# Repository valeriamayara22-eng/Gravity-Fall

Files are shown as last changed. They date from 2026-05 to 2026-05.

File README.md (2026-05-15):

# Gravity Fall: Gravitational Energy Storage System

**An open-source mechanical battery that converts gravitational potential energy into usable electricity.**






---

## Overview

Gravity Fall is a gravitational energy storage system designed and built by high school students in Mexico City. It demonstrates that gravitational potential energy can be reliably converted into usable electrical power — no solar panels, no wind turbines, no lithium batteries required.

The system works like a **mechanical battery**: a 15.65 kg mass is lifted to a height of 1.80 m. As it descends through a chain-driven transmission system, it spins a hub motor that generates electricity. A magnetic braking system controls the descent speed, while an MPPT charge controller regulates the output for stable energy storage.

**Key results:**
- Peak electrical output: **13W** at 1.02 N·m torque
- System efficiency: **58%** (gravitational PE → electrical energy)
- Angular velocity stabilization at **15.65 kg**, confirming successful magnetic brake control
- Stable descent time of **9.5 seconds** per cycle, validated by MPPT algorithm

> **⚠️ Important note:** This is a proof-of-concept prototype for energy storage research, not a practical energy generation device. Each 9.5-second descent cycle produces approximately 123.5 J of usable electrical energy. To fully charge an iPhone 16 (12.54 Wh battery), the mass would need to be lifted and released **394 times**. The value of this project lies in validating the physics, the control system, and the efficiency of gravitational-to-electrical conversion at small scale — not in replacing existing charging methods. The engineering challenge ahead is scaling: heavier masses, taller structures, and automated return systems could make this approach practical for real-world energy storage.

---

## The Problem

Over 770 million people worldwide lack access to reliable electricity. Existing renewable solutions (solar, wind) depend on weather conditions and often require expensive lithium-ion batteries for storage — batteries that degrade over time, require rare minerals to produce, and generate toxic waste.

Gravity Fall proposes an alternative: **store energy as height**. Unlike chemical batteries, a mass doesn't degrade. It can be lifted and dropped thousands of times with zero loss of storage capacity. The system requires no fuel, no rare materials, and no grid connection.

---

## System Architecture

```
┌─────────────┐
│  Mass (15.65 kg)  │
│  Height: 1.80 m   │
│  Ug = mgh         │
└───────┬─────┘
        │ Descent (gravity)
        ▼
┌─────────────┐
│  Chain Drive      │
│  Ratio: 1:9       │
│  Chains  │
└───────┬─────┘
        │ Mechanical torque
        ▼
┌─────────────┐
│  Hub Motor        │
│  Multi-pole       │
│  Magnetic brake   │
└───────┬─────┘
        │ AC output
        ▼
┌─────────────┐
│  MPPT Controller  │
│  Charge regulation│
└───────┬─────┘
        │ Regulated DC
        ▼
┌─────────────┐
│  LiFePO4 Battery  │
│  12V storage      │
└───────┬─────┘
        │ DC-DC conversion
        ▼
┌─────────────┐
│  USB-C Output     │
│  5V / Device      │
│  charging         │
└─────────────┘
```

---

## Prototype

| | |
|:---:|:---:|
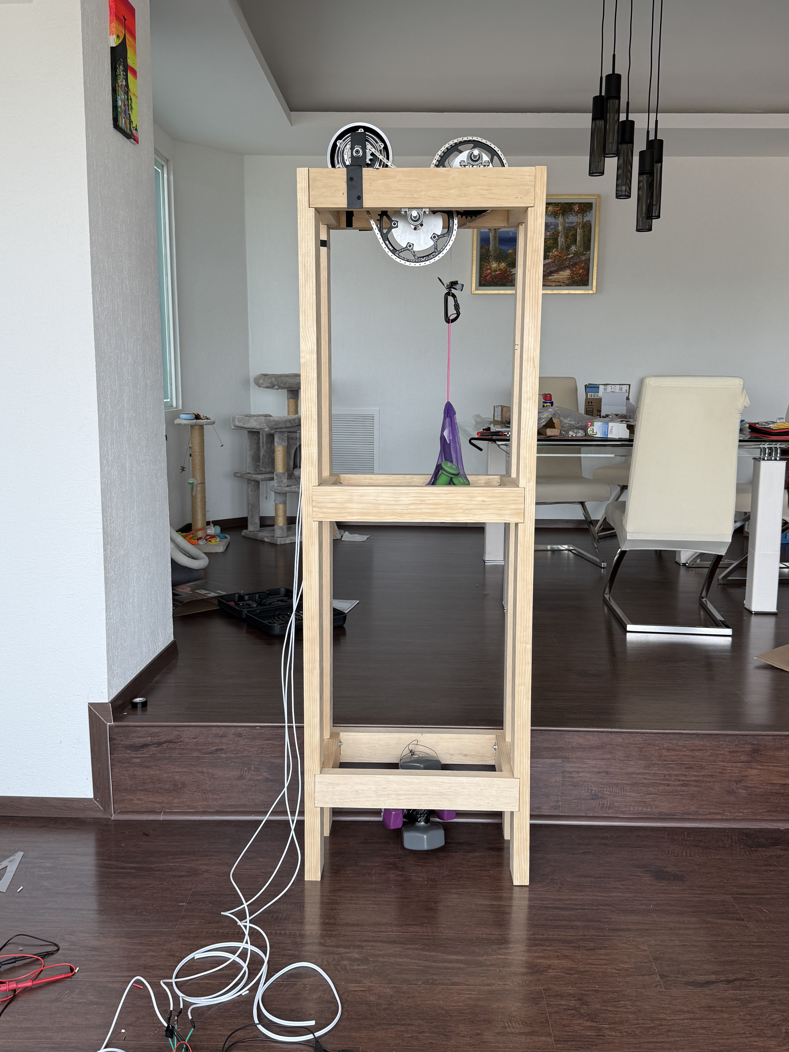
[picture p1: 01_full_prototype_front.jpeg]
Full prototype
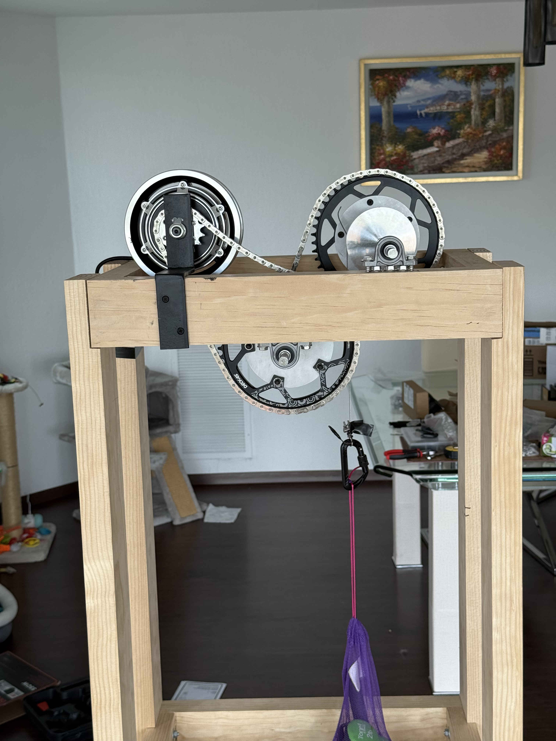
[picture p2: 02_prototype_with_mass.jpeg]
Prototype with mass
|  |  |
| *Complete structure — 1.80 m frame with chain drive and hub motor* | *Prototype with mass and descent mechanism* |
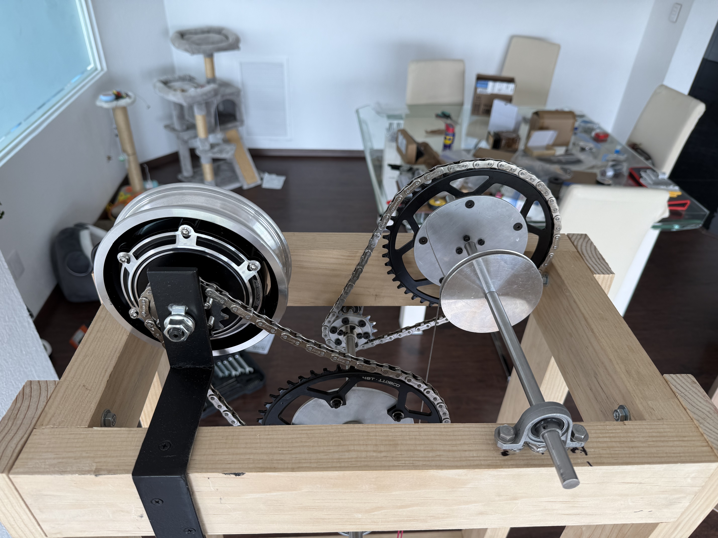
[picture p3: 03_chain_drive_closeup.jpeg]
Chain drive detail
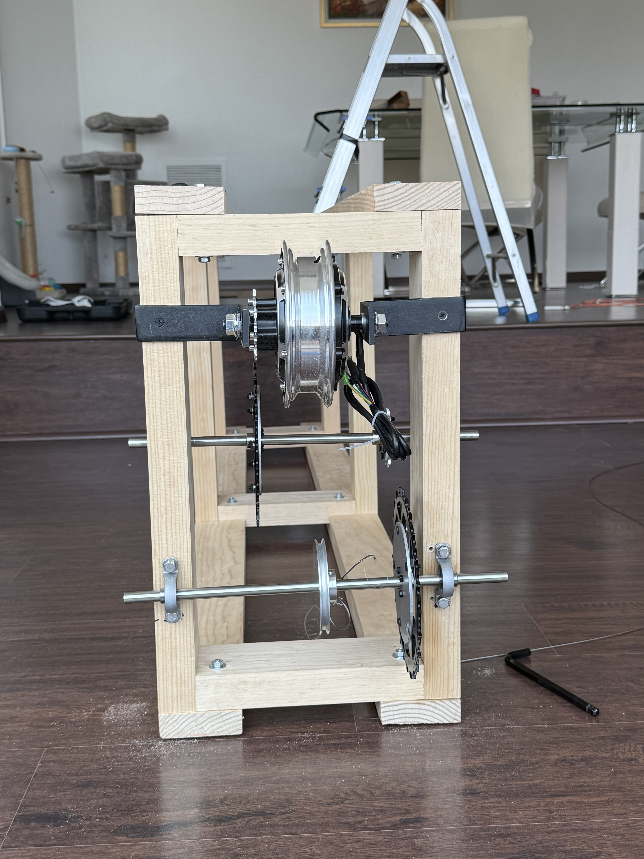
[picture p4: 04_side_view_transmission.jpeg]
Side view
|  |  |
| *Chain drive and sprocket system — 1:9 gear ratio* | *Side view showing full transmission path* |
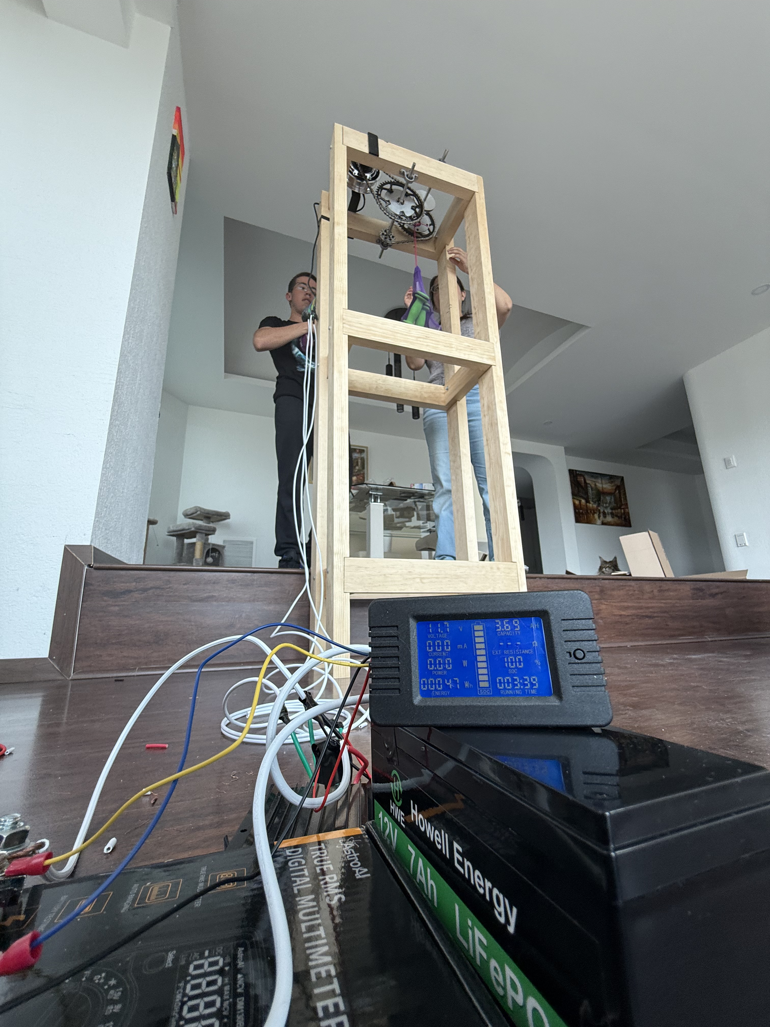
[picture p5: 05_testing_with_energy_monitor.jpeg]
Testing
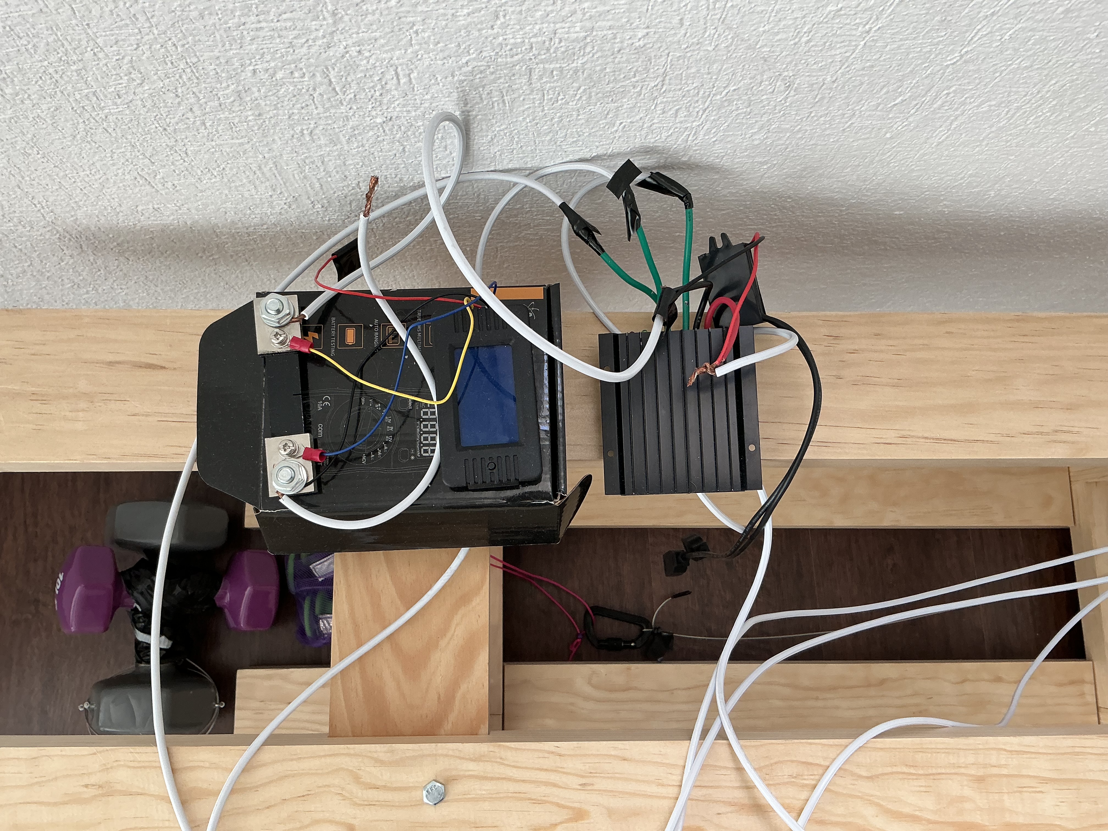
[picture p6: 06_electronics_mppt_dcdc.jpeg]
Electronics
|  |  |
| *Testing session with energy monitor and Howell Energy 12V 7Ah LiFePO4 battery* | *MPPT charge controller and DC-DC buck converter* |

| |
|:---:|
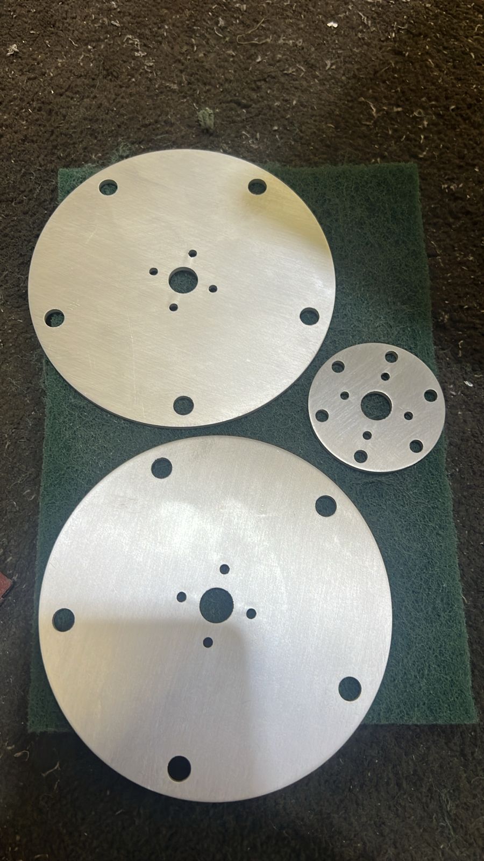
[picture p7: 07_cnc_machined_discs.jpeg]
CNC machined discs
|  |
| *Custom CNC-machined mounting discs — designed in FreeCAD* |

---

## Experimental Results

### Test Configuration
- **Structure height:** 1.80 m (1.39 m effective drop, 0.41 m dead space)
- **Transmission:** Bicycle chains, 1:9 gear ratio
- **Generator:** Multi-pole hub motor with magnetic braking
- **Energy management:** MPPT charge controller + DC-DC buck converter
- **Measurement instruments:** Multimeter, tachometer, torque sensor

### Performance Data

| Mass (kg) | Torque (N·m) | Power (W) | Efficiency (%) | Angular Vel. (rad/s) | Fall Time (s) |
|---|---|---|---|---|---|
| 10.05 | 0.65 | 5.1 | 40 | 7.85 | 9.50 |
| 12.85 | 0.83 | 8.7 | 49 | 10.48 | 9.50 |
| 15.65 | 1.02 | 13.0 | 58 | 12.75 | 9.50 |

### Key Findings

1. **Non-linear power scaling:** While mass increased by 56%, electrical power output jumped by **155%** (5.1W → 13W). This occurs because at lower loads, friction dominates; at higher loads, the motor operates in its optimal efficiency range.

2. **Efficiency scales with load:** Global efficiency improved from 40% to 58% with a slope of 3.18 per kg. Each additional kilogram of mass proportionally reduces frictional losses.

3. **Angular velocity stabilization:** At 15.65 kg, angular velocity varied by only 0.01 rad/s despite increasing mass — definitive proof that the magnetic braking system successfully controls descent speed while allowing power output to continue increasing.

4. **Constant fall time:** The 9.5-second descent remained stable across all mass configurations, validating the MPPT algorithm's ability to regulate energy extraction.

---

## Design Files

```
FreeCAD parametric models (.FCStd):
  ├── frame_structure.FCStd        → Main wooden frame
  ├── large_mounting_disc.FCStd    → Large disc for sprocket mounting
  ├── small_mounting_disc.FCStd    → Small disc for motor coupling
  └── metal_bracket.FCStd          → Metal bracket for hub motor support

Experimental data:
  └── experimental_results.xlsx    → All test measurements across three mass configurations

Documentation:
  └── BUILD_GUIDE.md               → Step-by-step construction guide with BOM
```

---

## Bill of Materials

### Prototype Cost (as built)

| Component | Source | Cost (MXN) |
|---|---|---|
| Custom wooden frame | Professional carpentry (commissioned) | $4,000 |
| Custom machined discs and supports | CNC machining from FreeCAD files | $3,500 |
| Hub motor (36V, multi-pole) | Online marketplace | $2,500 |
| Steel axles and bearings | Industrial supplier | $1,500 |
| MPPT charge controller | Electronics supplier | $1,200 |
| LiFePO4 battery (12V) | Electronics supplier | $2,000 |
| DC-DC buck converter (12V→5V) | Electronics supplier | $300 |
| Recycled bicycle chains | Local bike shop / scrap | $200 |
| Neodymium magnets (braking system) | Online marketplace | $500 |
| Sprockets and mounting hardware | Hardware store | $800 |
| Wiring, connectors, misc | Electronics supplier | $500 |
| **Total (as built)** | | **$15,000–$20,000 MXN (~$860–$1,150 USD)** |

### Estimated DIY Replication Cost

| Component | DIY Alternative | Est. Cost (MXN) |
|---|---|---|
| Frame | Self-built with lumber from hardware store | $800 |
| Custom parts | 3D printed from provided FreeCAD files | $500 |
| Hub motor | Same (no cheaper alternative) | $2,500 |
| Axles and bearings | Hardware store sourcing | $600 |
| MPPT controller | Budget unit from online marketplace | $600 |
| LiFePO4 battery | Budget unit from online marketplace | $1,200 |
| DC-DC converter, chains, magnets, wiring | Same sources | $800 |
| **Total (DIY estimate)** | | **~$7,000 MXN (~$400 USD)** |

*Our prototype used professionally fabricated components for precision and durability. The FreeCAD design files are provided so builders can choose between professional fabrication, 3D printing, or manual construction based on their available tools and budget.*

---

## Areas for Improvement

- **Dead space reduction:** 41 cm of the 1.80 m structure is non-functional. Compacting the design would increase effective gravitational potential by ~30%.
- **Chain-to-belt conversion:** Replacing chains with timing belts would reduce the current 10% frictional loss.
- **Automated mass return:** Implementing a motorized or manual winch system for re-lifting the mass would enable continuous operation.
- **Multi-mass parallel system:** Running multiple masses in sequence could provide near-continuous power output.

---

## Relevance

This project directly addresses **UN Sustainable Development Goal 7: Affordable and Clean Energy**. The system is:

- **Climate-independent** — works day or night, rain or shine
- **Zero-emission** — no combustion, no chemical processes
- **Non-degrading** — unlike lithium batteries, the mass never loses capacity
- **Low-cost and replicable** — DIY replication estimated at ~$400 USD using accessible materials and provided design files
- **Educational** — demonstrates core physics principles (energy conservation, electromagnetic induction, mechanical advantage) through a functional device

---

## Background

Gravity Fall was developed as a research project for the XIV Student Research Congress of the UNAM Incorporated System (CEISI 2026) in Mexico City. The project was presented in the Physics (Experimental) category and evaluated across three phases: research protocol, written report, and oral defense before a panel of judges.

The concept builds on existing gravitational energy storage technologies:
- **[Gravity Storage](https://gravity-storage.com/)** — Industrial-scale hydraulic gravity storage
- **[GravityLight](https://www.researchgate.net/publication/324211262)** — Gravity-powered lighting for off-grid communities
- **[Huisman Equipment](https://www.huismanequipment.com/)** — Gravity energy storage demonstrator in Edinburgh

---

## Team

- Mayara Valeria Peláez Beltrán 
- Leonardo Bojorquéz Berni
- Sebastián Dussauge Vaca 

*Developed at Liceo Mexicano Japonés, A.C. — Mexico City, Mexico*

---

## License

This project is open source under the [MIT License](LICENSE). You are free to replicate, modify, and distribute this design. If you build your own version, we'd love to hear about it.

---

## Contact

For questions, collaboration proposals, or if you've replicated this design in your community:

📧 [valeriamayara22@gmail.com]

---

*"The future of energy can be written following the most fundamental laws of physics."*

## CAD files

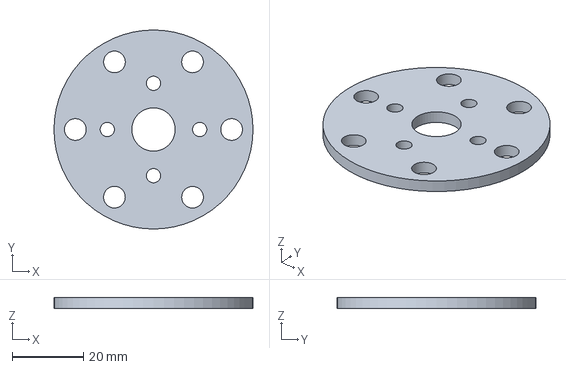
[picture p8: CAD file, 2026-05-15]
small_mounting_disc.FCStd
56.0 x 56.0 x 3.00 mm

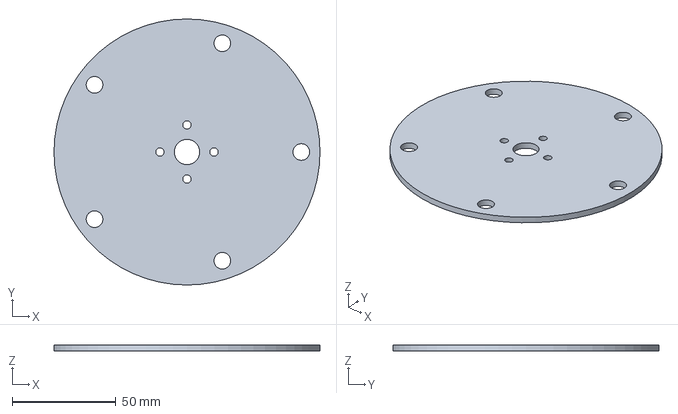
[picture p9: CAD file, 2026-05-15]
large_mounting_disc.FCStd
128.0 x 128.0 x 3.00 mm

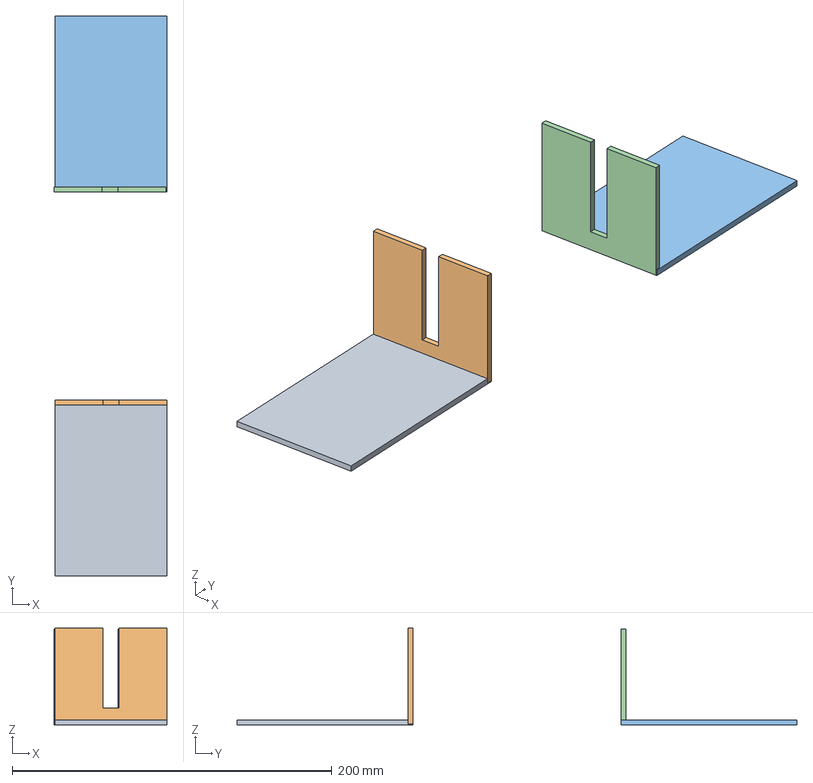
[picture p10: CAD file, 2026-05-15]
metal_bracket.FCStd
70.6 x 350.0 x 60.4 mm
Cuerpo
Cuerpo001
Cuerpo002

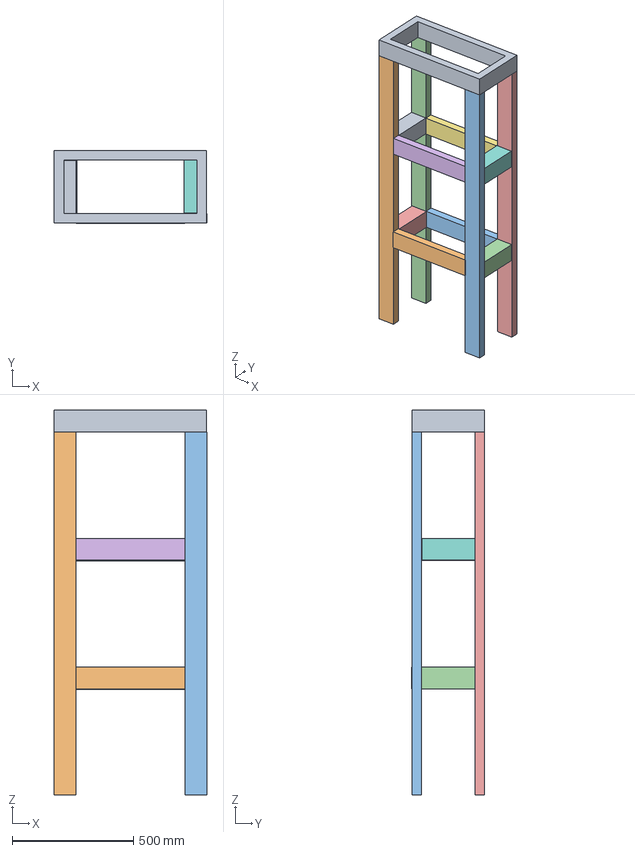
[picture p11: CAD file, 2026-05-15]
frame_structure.FCStd
630.3 x 303.0 x 1590.0 mm
Cuerpo
pata
Cuerpo001
Cuerpo002
Cuerpo003
Cuerpo005
Cuerpo006
Cuerpo007
Cuerpo008
Cuerpo009
Cuerpo011
Cuerpo012
Cuerpo013

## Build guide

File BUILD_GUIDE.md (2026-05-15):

# Gravity Fall — Build Guide

## How to Build a Gravitational Energy Storage System for ~$400 USD

*This guide will walk you through building a mechanical battery that converts gravitational potential energy into usable electricity. No industrial tools required.*

---

## What You'll Build

A system where a heavy mass (15.65 kg) descends from 1.80 m through a chain-driven transmission, spinning a hub motor that generates up to 13W of electricity at 58% efficiency. The output is regulated and stored in a battery, then converted to 5V USB for device charging.

**Difficulty:** Intermediate (basic mechanical assembly + basic electrical wiring)
**Time:** 2-3 weekends
**Cost:** ~$7,000 MXN / ~$400 USD (DIY) | $15,000-$20,000 MXN if professionally fabricated
**Tools needed:** Wrench set, screwdriver, soldering iron, multimeter, drill

---

## Bill of Materials

### Mechanical

| # | Component | Specification | Qty | Source | Est. Cost (MXN) |
|---|---|---|-----|---|---|
| 1 | Wooden beams | 2" x 4" x 2m | 4 | Hardware store | $500 |
| 2 | Bicycle chains | Standard | 2 | Bike shop | $200 |
| 3 | Large sprocket | ~20 teeth | 1 | Bike shop | $150 |
| 4 | Small sprocket | Custom (1:9 ratio) | 1 | 3D print / machined | $300 |
| 5 | Steel axles | 12mm diameter | 2 | Hardware store / industrial | $400 |
| 6 | Bearings | 6201-2RS (12mm bore) | 4 | Hardware store | $200 |
| 7 | Mass container | Bucket or custom frame | 1 | Recycled | $0 |
| 8 | Sand/weights | To reach 15.65 kg total | — | Local | $50 |
| 9 | Mounting hardware | Bolts, nuts, brackets | — | Hardware store | $200 |

### Electrical

| # | Component | Specification | Qty | Source | Est. Cost (MXN) |
|---|---|---|-----|---|---|
| 10 | Hub motor | 36V, multi-pole | 1 | Online | $2,500 |
| 11 | Neodymium magnets | For magnetic brake | 4-6 | Online | $500 |
| 12 | MPPT charge controller | 10A, adjustable | 1 | Electronics store | $600 |
| 13 | LiFePO4 battery | 12V, 6Ah minimum | 1 | Electronics store | $1,200 |
| 14 | DC-DC buck converter | 12V→5V, 3A | 1 | Electronics store | $300 |
| 15 | USB-C breakout board | Female, for output | 1 | Electronics store | $50 |
| 16 | Wiring | 14-16 AWG, silicone | 2m | Electronics store | $100 |

**Estimated DIY total: ~$7,000 MXN (~$400 USD)**

*Note: Our prototype cost $15,000–$20,000 MXN because we commissioned professional carpentry and CNC machining for the frame and custom parts. The estimates above assume you build the frame yourself and 3D print custom components from the provided FreeCAD files.*

---

## Step 1: Build the Frame

**Goal:** A rigid vertical structure that supports the mass descent path and motor assembly.

1. Cut four 2m wooden beams to your desired height (we used 1.80 m effective height).
2. Assemble a rectangular frame using bolts — not nails. You need rigidity without vibration.
3. Mark the motor mounting position at the bottom and the release mechanism position at the top.
4. Ensure the frame is perfectly vertical. Use a level. Any tilt will cause the mass to swing during descent.

**Critical dimension:** The effective drop height is your total height minus the motor assembly space and top mechanism. In our case: 1.80 m total, 1.39 m effective drop, 0.41 m dead space. Minimize dead space.

---

## Step 2: Install the Chain Drive

**Goal:** A 1:9 gear ratio transmission that multiplies the slow descent into fast motor rotation.

1. Mount the large sprocket (driven) on the mass descent axle.
2. Mount the small sprocket (driver) on the motor axle.
3. Connect with the bicycle chain. Ensure proper tension — too loose and it skips, too tight and friction increases.
4. Test by hand: rotating the large sprocket one full turn should spin the small sprocket approximately 9 times.

**Why 1:9?** A falling mass moves slowly. The hub motor needs higher RPM to generate meaningful voltage. The gear ratio bridges this gap. We tested 1:5 first — it was insufficient. The jump to 1:9 was the single most impactful design change.

**Tip:** Clean and lubricate chains thoroughly before installation. Chain friction accounted for ~10% energy loss in our system.

---

## Step 3: Mount the Hub Motor and Magnetic Brake

**Goal:** Controlled energy extraction from the descending mass.

1. Secure the hub motor to the frame at the small sprocket position.
2. Position neodymium magnets around the motor's rotating element to create eddy current braking.
3. Adjust magnet distance to control braking force. Closer = more braking = slower descent = more controlled output.
4. Test: the mass should descend smoothly over ~9-10 seconds. If it falls faster, add braking force. If it barely moves, reduce it.

**Why magnetic braking?** Without it, the mass accelerates under gravity and the motor spins too fast, producing voltage spikes that can damage the electronics. The magnetic brake provides smooth, consistent energy extraction.

---

## Step 4: Wire the Electrical System

**Goal:** Convert the motor's AC output into stable, stored DC power.

```
Hub Motor (AC out) → MPPT Controller (input) → LiFePO4 Battery (12V) → DC-DC Converter → USB-C (5V out)
```

1. Connect the hub motor output wires to the MPPT controller input.
2. Connect the MPPT output to the LiFePO4 battery terminals (observe polarity!).
3. Connect the battery output to the DC-DC buck converter input.
4. Set the DC-DC converter output to 5V using the adjustment potentiometer.
5. Wire the DC-DC output to the USB-C breakout board.
6. Verify all connections with a multimeter before first test.

**Safety:** LiFePO4 batteries are among the safest lithium chemistries, but always include a fuse between the battery and the DC-DC converter. Never short-circuit the battery terminals.

---

## Step 5: Test and Measure

**Goal:** Validate performance and gather data.

### Measurements to take:
- **Voltage** at motor output, battery terminals, and USB output (multimeter)
- **Fall time** for each mass configuration (stopwatch)
- **Mass** of the descending weight (scale)

### Calculated values:
- **Gravitational PE:** Ug = m × g × h (in Joules)
- **Electrical energy:** P × t (Power × time, in Joules)
- **System efficiency:** (Electrical energy out / Gravitational PE in) × 100%

### Test protocol:
1. Start with your lowest mass. Measure and record.
2. Increase mass by 2-3 kg increments. Measure and record each time.
3. Plot at least three data points for: Efficiency vs Mass, Power vs Torque, Angular Velocity vs Mass.
4. Look for the stabilization point — where adding more mass no longer increases speed but continues increasing power. That's your optimal operating range.

---

## Step 6: Iterate

Your first build will not hit 58% efficiency. Ours didn't either. Here's what to look for:

| Problem | Likely Cause | Fix |
|---|---|-----|
| Mass barely moves | Too much magnetic braking or too much chain friction | Reduce magnets or lubricate chain |
| Mass falls too fast | Not enough braking | Add magnets or move them closer |
| Low voltage output | Motor RPM too low | Increase gear ratio or add mass |
| Voltage spikes | Uncontrolled descent speed | Adjust magnetic brake for stability |
| Battery not charging | MPPT settings incorrect | Reconfigure MPPT for your battery chemistry |

---

## Your Results vs Ours

| Metric | Our Prototype | Your Build |
|---|---|---|
| Peak Power | 13W | _______ W |
| Efficiency | 58% | _______ % |
| Fall Time | 9.5 s | _______ s |
| Best Mass | 15.65 kg | _______ kg |

Share your results! Open an issue on the GitHub repository or tag us on social media.

---

## Safety Notes

- The descending mass carries significant kinetic energy. Keep hands and feet clear during operation.
- Secure the frame to a wall or floor to prevent tipping.
- Never exceed the structural capacity of your frame.
- Use proper electrical safety: fuses, insulated connections, no exposed terminals.
- LiFePO4 batteries are safe but should never be punctured, shorted, or overcharged beyond 14.6V.

---

## License

This build guide is released under the MIT License. Build it, modify it, share it. If you improve the design, submit a pull request.

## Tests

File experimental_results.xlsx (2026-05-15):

Fuerza 1 | 10kg |  | Fuerza 2 | 13.64kg |  | Fuerza 3 | 15.65kg
Potencia | 5.1W |  | Potencia | 10.4W |  | Potencia | 13W
Tiempo de bajada | 10s |  | Tiempo de bajada | 9.63s |  | Tiempo de bajada | 9.56s
Energía | 0.014166Wh |  | Energía | 0.02782Wh |  | Energía | 0.0339911Wh
Energía potencial | 0.035425Wh |  | Energía potencial | 0.05150Wh |  | Energía potencial | 0.059097Wh
Eficiencia | 40% |  | Eficiencia | 54% |  | Eficiencia | 58%
Veces para carga | 1406 |  | Veces para carga | 493 |  | Veces para carga | 394
Masa (kg) | Torque Motor (N·m) | Potencia Generada (W) | Eficiencia (%) | Caídas para carga | Velocidad angular (rad/s)
10 | 0.65 | 5.1 | 40% | 1406 | 2.32
13.64 | 0.89 | 10.4 | 54% | 493 | 2.41
15.65 | 1.02 | 13 | 58% | 394 | 2.42
Masa (kg) | Eficiencia (%)
10 | 40%
13.64 | 54%
15.65 | 58%
Torque Motor (N·m) | Potencia Generada (W)
0.65 | 5.1
0.89 | 10.4
1.02 | 13
Masa (kg) | Velocidad angular polea (rad/s)
10 | 2.32
13.64 | 2.41
15.65 | 2.42

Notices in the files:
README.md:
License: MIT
